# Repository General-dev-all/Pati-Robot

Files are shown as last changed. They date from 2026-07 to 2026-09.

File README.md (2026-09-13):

# Pati

A voice companion robot for children, built on an ESP32-S3.

Pati runs no local model. Audio streams from the device to the Gemini
Live API over a raw WebSocket and returns to the speaker the same way.
No companion app, no intermediate server, no pairing step. Settings are
managed from a web panel served by the robot itself.

The hardware is one part — an M5Stack StickS3 — with the microphone,
speaker, display and battery already inside it. Nothing is soldered.

<p align="center">
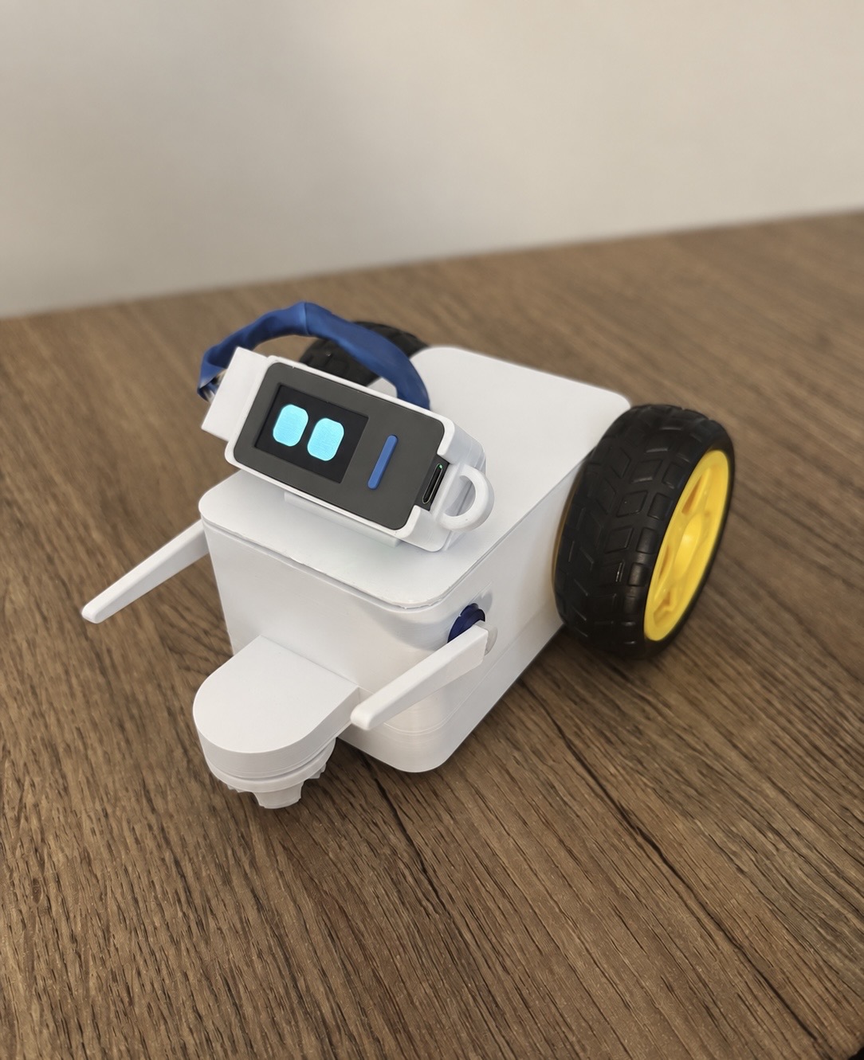
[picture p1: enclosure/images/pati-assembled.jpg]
Pati, assembled
  
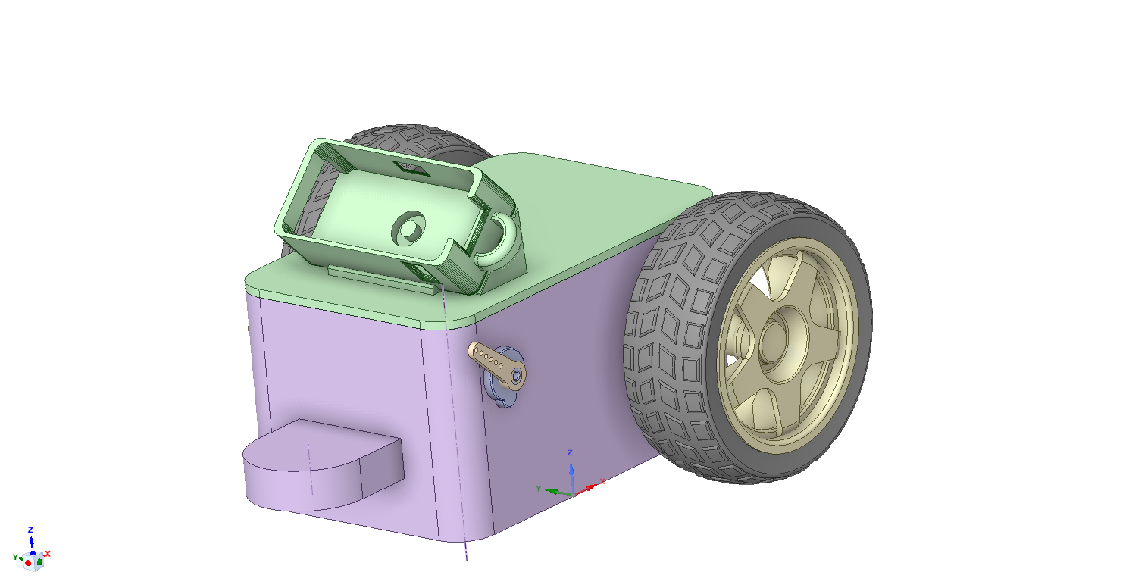
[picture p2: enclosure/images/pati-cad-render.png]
Pati in CAD
  
</p>
<p align="center"><sub>The printed body, assembled &nbsp;·&nbsp; the same assembly in CAD</sub></p>

<p align="center">
  <a href="https://www.youtube.com/watch?v=BEeX3aKE_l4">
    Pati in action — watch on YouTube
  </a>
</p>
<p align="center"><a href="https://www.youtube.com/watch?v=BEeX3aKE_l4"><b>▶ Watch Pati in action</b></a></p>

The body is optional and printable — STLs and editable CAD source are in
[`enclosure/`](enclosure/). Without it Pati still talks, listens and
shows its eyes; the body adds two wheels and two arms.

**Status.** Microphone, speaker, display, eyes, Wi-Fi, panel and Gemini
conversation were verified on a real StickS3 on September 1, 2026.
Battery operation is still unstable: speaking can trigger a reset.
The September 5 code review fixed a playback-related eye power-mode bug;
its effect on real battery resets still needs device testing. See
[`firmware/PIL.md`](firmware/PIL.md) for measurements and remaining work.

---

## Layout

```
firmware/    ESP-IDF v5.5 application
panel/       Parent panel — one web page, served from disk during
             development and compiled into the firmware for the device
prototype/   Python reference implementation; the host tests compare
             firmware behaviour against it
enclosure/   The printable body: STLs ready to slice, editable CAD
             source, and the assembly notes
```

The devkit's assembly guide, wiring diagram and printed parts are not
here. They describe hardware that no longer exists, so they live with
it on the `devkit` branch rather than misleading anyone on `main`.

`panel/` is a single source. The page is not duplicated for the device
build, so a firmware update carries the panel with it.

---

## Hardware

One part. **M5Stack StickS3** (SKU K150) — nothing is wired, nothing is
soldered.

| Inside it | |
|---|---|
| ESP32-S3-PICO-1-N8R8 | 8 MB flash, 8 MB octal PSRAM |
| ES8311 | mono audio codec, configured over I2C, one shared I2S bus |
| MEMS microphone | 65 dB SNR |
| AW8737A + 8 Ω 1 W speaker | amplifier enabled through the M5PM1, not from a GPIO |
| ST7789P3 | 135×240 display, used in landscape as 240×135 |
| M5PM1 | power management, battery charging, the power button |
| 250 mAh battery, 2 buttons, BMI270 IMU, IR | 48 × 24 × 15 mm |

Pin assignments have a single source:
[`firmware/main/pati_pinler.h`](firmware/main/pati_pinler.h).

Three things about this board are not obvious and each one fails
silently:

**The microphone, the speaker and the display backlight are not powered
at boot.** They sit on the M5PM1's `L3B` rail, which the Arduino library
turns on during its own init. On bare ESP-IDF nothing turns it on for
you. Miss it and all three are dead while every call still returns
`ESP_OK`. [`pati_guc.cpp`](firmware/main/pati_guc.cpp) does it.

**The microphone and the speaker share one I2S bus, so they share one
sample rate.** Gemini wants 16 kHz in and gives 24 kHz out; neither is
possible directly. The bus runs at 48 kHz and both directions are
resampled — see [Voice](#voice).

**Use the verified ESP32 signal directions:** GPIO14 is output to the
codec (speaker), GPIO16 is input from the codec (microphone). The
peripheral row label led to these being reversed during the first port.

First boot, step by step, with the symptom-to-line mapping for
everything that cannot be checked without the board:
[`firmware/ILK-ACILIS.md`](firmware/ILK-ACILIS.md) (Turkish).

### The previous Pati

Until August 2026 this was a hand-wired ESP32-S3 devkit with an INMP441,
a MAX98357A and a 240×240 display — thirteen soldered wires. It works
and is kept, not deleted:

```
git switch --detach v2.2.8-devkit     # source
```

Its built `pati.bin` is in the `v2.2.8` release. The branch also carries
what `main` no longer does: `assembly/REHBER.html` (the soldering guide,
Turkish), the wiring diagram, and **that board's** printed parts — which
are not the ones in [`enclosure/`](enclosure/). Those describe a device
that no longer exists.

⚠️ **Do not run this firmware on that board.** Same chip family, so it
flashes and boots, and the update manifest carries no hardware field. It
refuses to run instead: at boot it probes for the ES8311 and, if absent,
declines to mark itself valid so the bootloader rolls back. That
recovery only exists for an image that arrived over the air — one
flashed by cable has nothing to roll back to.

---

## Body

Pati works on its own. The body is optional: it adds two driven wheels
and two servo arms, and it prints on a home 3D printer. Files, parts
list and assembly notes are in [`enclosure/`](enclosure/).

🔴 **The two front wheels must be ball casters, and they print too**
(`enclosure/print/ball-caster.stl`, print-in-place — the ball comes out
of the printer already turning inside its socket). This is not a styling
choice. With fixed-axle front wheels the chassis sits on a rail: it
rolls freely fore and aft but resists sliding sideways, so the torque
that cannot become rotation escapes along the only unresisted axis and
**Pati creeps forward while turning in place**. Three firmware releases
tried to fix that in software and none of them could — the gesture table
already sums to zero rotation by construction. Swapping the front wheels
ended it.

🔴 **Pati turns in place. It never drives itself anywhere.** There is no
cliff sensor, so a robot that could travel on its own would eventually
walk off a table. The whole gesture system is built around one
guarantee: the two wheels always turn in opposite directions, so net
displacement is zero. Driving across a table is possible only from the
panel, under a child's finger, behind a 600 ms dead-man timer.

🔴 **Motor and servo power never reaches the StickS3.** Every one of the
eight wires from the body to the Stick is either ground or the Stick's
own output; the 6 V rail stays inside the body. This is not a caution
note — it is the reason the pins were chosen that way. With the rule set
up like this, the worst outcome of a wire slipping onto the wrong pin is
"a motor runs continuously", not a dead board.

### Wiring

Wire colors in both diagrams match the real assembly. Same diagram, two
languages — the parts and pin numbers are identical.

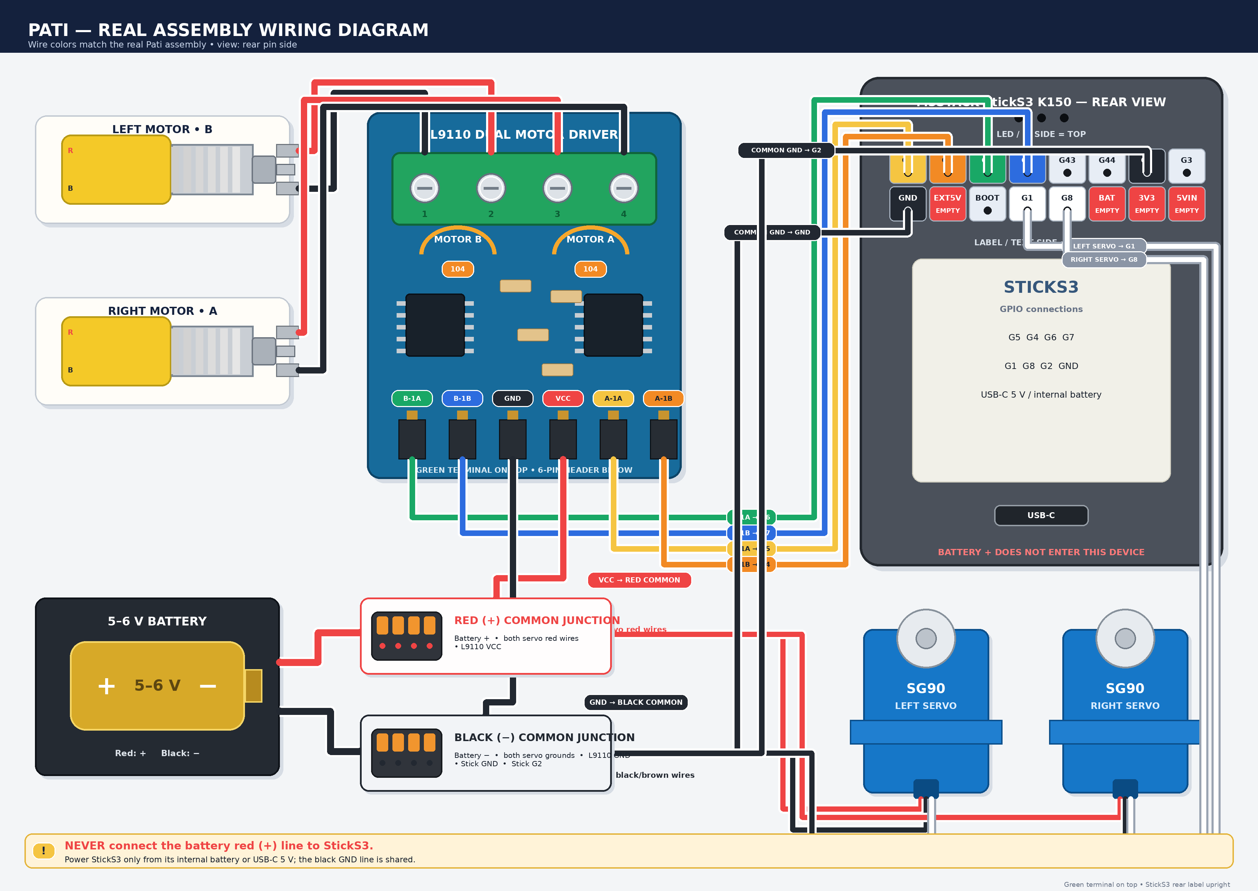
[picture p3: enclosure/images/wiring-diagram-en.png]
Wiring diagram, English


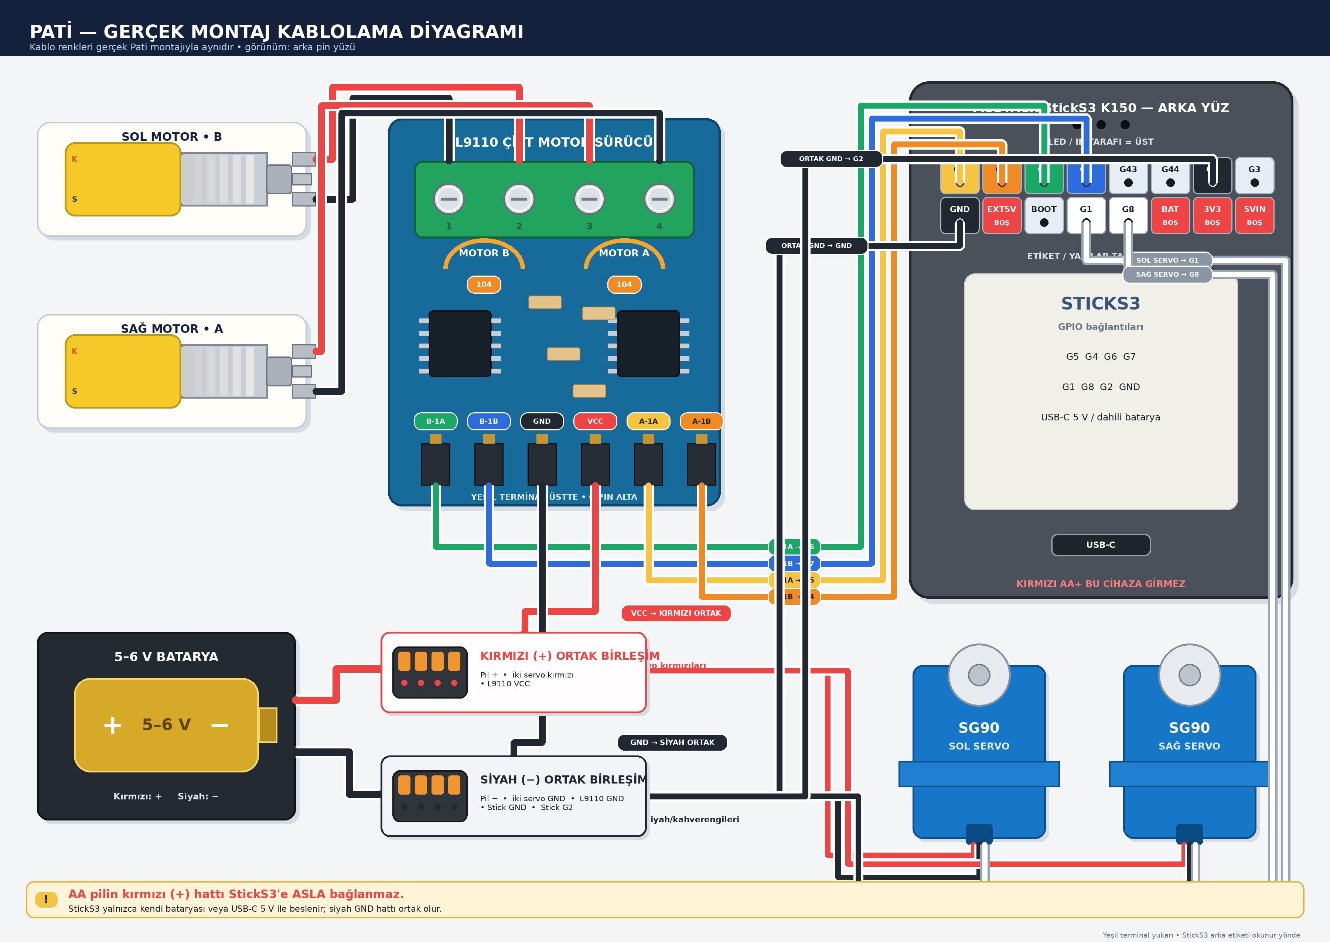
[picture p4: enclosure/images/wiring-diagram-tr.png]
Kablolama diyagramı, Türkçe


There is a third, different document:
[`firmware/Pati_Tek_Bakis_Kablolama_Diyagrami.png`](firmware/Pati_Tek_Bakis_Kablolama_Diyagrami.png)
(Turkish) is not another copy of these — it is the step-by-step pin
table: which way to hold the connector, the L9110 pin map, the power
junctions, and the first-power-up checklist. Use the diagrams above to
see *where the wires go*, and that one to check *each pin before
switching on*.

Pin assignments, commissioning measurements and the numbers still
waiting to be measured: [`firmware/BEDEN.md`](firmware/BEDEN.md)
(Turkish).

---

## Build

Requires ESP-IDF v5.5. On Windows use PowerShell — `idf_tools.py`
refuses to run under MSYS.

```
. "$IDF_PATH/export.ps1"
cd firmware
idf.py -p <PORT> flash monitor
```

Nothing to fill in first. The Wi-Fi credentials and the Gemini key are
both entered on the device — the first through the captive portal, the
second through the panel.

`firmware/KARTA-YUKLE.bat` does the same on Windows and finds the
serial port itself.

No API key is built in. The Gemini key is entered from the parent panel
and stored on the device, so the image contains no secret and can be
published. The partition table is custom
([`firmware/partitions.csv`](firmware/partitions.csv)) and must be
written over USB — `idf.py flash`, not `app-flash`.

## Updates

Push. GitHub builds the firmware and publishes a release holding
`pati.bin` and a generated `surum.json`; the device polls the latter and
downloads the former. No update server, no companion app, nothing to
upload by hand. Details in
[`firmware/SURUM-NASIL-CIKARILIR.md`](firmware/SURUM-NASIL-CIKARILIR.md).

CI picks the version rather than asking for it: the patch of the last
release, plus one. A larger number written into
[`firmware/surum.txt`](firmware/surum.txt) by hand is honoured, a
smaller one ignored. The line under it is the single sentence the parent
sees, and a release with no note is refused.

Publishing on every push is deliberate here. Forgetting to raise a
version produced no error and no release — the robot simply stayed
behind and nothing said so. A push to this repository means the change
was tested and is meant to reach the child's room, so that is what it
does. Only `firmware/` and `panel/` trigger it, since only those end up
in the image.

The manifest is a release asset rather than a committed file because a
push publishes a committed file immediately but does not build the
binary. For the minutes in between, the panel would offer an update that
404s. Sharing a release makes the manifest unable to exist before the
image it describes.

The binary is not committed. The panel is compiled into it, so a panel
change ships as a firmware update — which is why the two cannot drift.

The build needs no secrets, which is what makes CI possible at all: the
key and the Wi-Fi credentials both live in the device's NVS, and no
source file reads them from the configuration.

Rollback is enabled: a new image boots on trial and is only marked good
once the network stack and panel are up. An image that cannot get that
far is reverted by the bootloader on the next power cycle.

---

## Voice

Pati sounds like a child. That is not a Gemini setting — the Live API
exposes no pitch or rate control, only a voice name. Puck's raw voice is
an adult man's. The character comes entirely from **playing the reply
1.30× fast**, which raises the pitch by about the same amount.

On the old board this was one line: run the speaker's I2S clock at
31 200 Hz instead of 24 000. The StickS3 cannot do that — the speaker
shares its clock with the microphone, and moving it would break capture.

So the multiplier moved into software. The bus runs at 48 kHz and every
output sample steps `çarpan / 2` through the 24 kHz source — 0.65 at
1.30× — interpolating between samples. The step is always below 1
across the whole adjustable range (0.80–1.60 → 0.40–0.80), which is the
point: below 1 you interpolate and nothing aliases. Above 1 you would be
decimating, and Pati would rasp.

Capture goes the other way: 48 kHz down to the 16 kHz Gemini wants, an
exact 3:1 ratio, averaging each group of three. The averaging is also a
crude low-pass, which plain decimation would not be.

[`pati_ornekleyici.hpp`](firmware/main/pati_ornekleyici.hpp) holds the
maths, and it is a header rather than part of `pati_ses.cpp` because the
host test includes the same file — the test measures the real code, not
a copy. It found two real defects: output drifting apart depending on
how the audio was sliced, and phase loss over a long stream. Both came
from accumulating position in a single `float`, whose precision decays
as the value grows. Position is now an integer index plus a fraction
kept in `[0, 1)`.

---

## Tests

```
firmware/test/derle.bat     C++ eye renderer vs. the browser renderer,
                            pixel by pixel; C++ memory engine vs. Python;
                            the resampler that produces Pati's voice
python prototype/testler.py prototype behaviour
node panel/panel_test.mjs   the panel loads against a stub DOM, in each
                            of the four sample data sets
```

`ses_karsilastir` also writes two WAVs from a raw 24 kHz Gemini capture,
for listening rather than asserting:

```
firmware/test/ses_karsilastir.exe --pcm kayit.pcm --cikti .
```

One is what the old board played, the other is what the new path
produces. They have to sound the same.

The panel check exists because a missing element makes `querySelector`
return null, and the resulting throw stops the module — so the failure
is not the card that was edited, it is every card below it. Nothing on
screen says why.

The host comparisons exist because a port that compiles is not a port
that behaves identically. Generated headers are produced by
`prompt_uret.py` and `goz_uret.mjs`, which read their output back and
compare it to the source; they are not edited by hand.

---

## Operation

With no reachable saved network the device opens its own access point
and serves a captive portal for Wi-Fi setup. Once connected it
advertises itself over mDNS and the panel is reachable at `pati.local`.

The panel covers voice and rate, response latency, sleep threshold,
usage and estimated cost, the robot's name, the facts it has retained,
the Gemini key, and firmware updates. The interface is Turkish only.

Setup is Wi-Fi, then the key. Until a key is entered the robot has a
face but no voice, and the panel says so rather than leaving the parent
to guess.

When Google rejects a request the panel distinguishes the cases, because
the parent's next action differs: a rejected key needs replacing, an
exhausted quota needs credit, and an unreachable network needs nothing
at all. Collapsing the three would invite paying for an outage.

---

## Privacy

No child data is committed here. API keys, Wi-Fi credentials, retained
memory, usage counters and transcripts are excluded by `.gitignore`.

On the device, memory is stored in NVS and written atomically, since
the expected shutdown is a power cut. It can be cleared from the panel.

---

## License

MIT — see [LICENSE](LICENSE), which also lists third-party components.

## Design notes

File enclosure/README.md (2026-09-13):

# Gövde — 3B baskı parçaları

**Gövde artık var ve basılabiliyor.** Bu klasör, Pati'yi kendi yapmak
isteyen biri için gereken bütün parçaları taşıyor: dilimleyiciye
doğrudan verilebilen STL'ler ve tasarımı değiştirmek isteyenler için
düzenlenebilir CAD kaynağı.

<p align="center">
  Pati, monte edilmis hali
  Pati, CAD gorunumu
</p>

---

## Ne nerede

### `print/` — dilimleyiciye doğrudan verilir

| Dosya | Ne |
|---|---|
| `body.stl` | Gövdenin kendisi. Motorlar, sürücü ve besleme bunun içinde |
| `body-top.stl` | Üst kapak. StickS3 yuvası bunun üzerinde |
| `arm.stl` | Kol. **İki adet basılıyor** — servo boynuzuna geçiyor |
| `sticks3-case.stl` | StickS3'ün kızağa oturan kasası |
| `sticks3-cable-plug.stl` | Hat2-Bus şerit kablosunu Stick'e hizalayan tutucu |
| `ball-caster.stl` | **Ön sarhoş teker.** İki adet basılıyor — aşağıya bak |

### `cad/` — tasarımı değiştirmek için

Üçü de **aynı montajın** farklı biçimleri:

| Dosya | Ne zaman |
|---|---|
| `pati-assembly.step` | **Önce bunu dene.** Her CAD programı okuyor |
| `pati-assembly.x_t` | Parasolid çekirdekli programlarda (SolidWorks, Solid Edge, NX) daha temiz geliyor |
| `pati-assembly.scdocx` | SpaceClaim'in kendi biçimi — tasarım ağacıyla birlikte |

⚠️ **STL'i düzenlemeye çalışma.** STL yalnızca üçgen yüzeyler tutuyor;
ölçüyü 2 mm büyütmek gibi bir şey orada ağrılı, CAD kaynağında bir
sayı. Değişiklik `cad/`'de yapılıp STL yeniden dışa aktarılmalı.

---

## 🔴 Ön tekerlekler DÖNEBİLEN (caster) olmalı — bu ölçülmüş bir ders

Gövdede dört tekerlek var: arkada iki tahrik tekerleği, önde iki
destek. **Öndekiler sabit akslı olursa Pati kendi etrafında dönerken
İLERİ KAYIYOR.**

Sebep mekanik: sabit bir tekerlek kendi ekseninde dirençsiz yuvarlanıp
yana kaymaya direniyor, yani gövdeyi bir rayın üstüne koyuyor. Dönüşe
çevrilemeyen kuvvet, direnç görmediği tek eksene — ileri — kaçıyor.

⚠️ **Bu yazılımdan düzeltilemiyor ve üç sürüm boyunca denendi.** Pati'nin
jest tablosunda net dönüş yapısal olarak sıfır (iki tekerlek her zaman
ters yönde) ve konak testi bunu her girdide tarıyor — yani komut zaten
doğruydu, kayan şey fizikti. Ön tekerlekler dönebilen (İngilizcesi
*ball caster*, Türkçede "sarhoş teker", satın alırken "üniversal bilya")
tipiyle değiştirilince kayma bitti (13.09.2026). Ayrıntı:
[`../firmware/BEDEN.md`](../firmware/BEDEN.md).

**Neden önemli:** Pati'de uçurum sensörü yok. Kendi kararıyla ilerleyen
bir robot eninde sonunda masadan düşer, ve bu tasarımın tamamı Pati'nin
yalnızca *yerinde dönmesi* üzerine kurulu.

### `ball-caster.stl` — satın almaya gerek yok, basılıyor

**Yerinde basılan (print-in-place) bir parça.** Yuva ve bilya tek
dosyada, ayrı ayrı montaj yok: baskı bitince bilya yuvanın içinde
kendiliğinden dönüyor.

Ölçüler dosyadan okundu, tahmin değil:

| | |
|---|---|
| Dış ölçü | 31 × 31 × 21 mm |
| Bilya çapı | 16,0 mm |
| Yuva–bilya boşluğu | **0,177 mm**, her yerde eşit |
| Adet | **2** (ön tekerleklerin ikisi de) |

🔴 **0,177 mm dar bir boşluk ve bu parçanın tek riski orada.** Yerinde
basılan parçalarda alışılmış aralık 0,2–0,4 mm; bu onun altında. İyi
ayarlanmış bir yazıcıda sorun çıkarmaz, ama fazla akıtan (over-extrude)
ya da kalibresi kaymış bir yazıcıda **bilya yuvaya kaynar ve dönmez**.

Belirtisi baskıdan hemen sonra anlaşılıyor: bilyayı parmakla
çeviremiyorsan kaynamıştır. Kurtarmayı denemek yerine akış oranını
düşürüp yeniden basmak daha hızlı — kaynamış bir bilyayı zorlamak
yuvayı kırıyor.

⚠️ **Dönmeyen bir sarhoş teker, sabit akslı tekerlekle aynı şeydir** —
yani yukarıdaki ileri kayma sorunu geri gelir. Bu parça basıldıktan
sonra **ikisi de elle kontrol edilmeli.**

---

## Baskı dışında gereken parçalar

| Parça | Not |
|---|---|
| 2 × TT redüktörlü DC motor + tekerlek | sarı, yaygın tip |
| ~~2 × dönebilen ön tekerlek~~ | **satın alma — `ball-caster.stl` basılıyor** |
| 1 × L9110S çift kanal motor sürücü | |
| 2 × SG90 sınıfı mini servo | kollar |
| Besleme | 4'lü AA yuvası **ya da** powerbank |
| M5Stack StickS3 (SKU K150) | Pati'nin kendisi |

🔴 **Motor ve servo beslemesi StickS3'ten ALINMIYOR.** Gövdeden Stick'e
giden sekiz kablonun hepsi ya toprak ya Stick'in kendi çıkışı; 6 V
hattı gövdenin içinde kalıyor. Bu bir uyarı değil, **pin seçiminin
sebebi**: kural böyle kurulunca yanlış pine kayan bir kablonun en kötü
sonucu "motor sürekli dönüyor" oluyor, yanmış bir kart değil.

### Kablolama

Her iki diyagramdaki kablo renkleri **gerçek montajla aynı**. Aynı
şema, iki dil — parçalar ve pin numaraları birebir.

Kablolama diyagramı, Türkçe

Wiring diagram, English

⚠️ **Üçüncü bir belge daha var ve o bunların kopyası DEĞİL:**
[`../firmware/Pati_Tek_Bakis_Kablolama_Diyagrami.png`](../firmware/Pati_Tek_Bakis_Kablolama_Diyagrami.png)
adım adım **pin tablosu** — soketin hangi yönde tutulacağı, L9110 pin
haritası, ortak güç birleşimleri ve ilk çalıştırma kontrol listesi.

**Hangisi ne zaman:** yukarıdaki şemalar *kablo nereye gidiyor* diye
bakarken, pin tablosu *açmadan önce her pini tek tek doğrularken*.

⚠️ İkisinin dosya adı benziyor ama içerikleri farklı. Birini
diğerinin yerine kullanmak, doğruladığını sanıp doğrulamamak olur.

Pin atamaları ve devreye alma ölçümleri:
[`../firmware/BEDEN.md`](../firmware/BEDEN.md)

---

## Monte ederken

🔴 **Kolun gidebileceği aralık MEKANİK bir sınır.** Bu gövdede ölçüldü
(09.09.2026): sol kol **%10–%70**, sağ kol **%0–%100**. Sol kol aşağıda
tekerleğe, yukarıda üstteki kabloya çarpıyor. Aşılırsa kol dayanır,
servo dönmeye çalışıp durur, ısınır ve **yanar** — belirtisi sürekli
bir vızıltıdır.

Aralık panelden ayarlanıyor ve **fabrika ayarlarına dönünce
silinmiyor**; kaybolması donanıma zarar verdiği için ayrı bir flash
bölümünde duruyor.

⚠️ **Servolar ters takılabilir** ve ikinci gövdede öyle oldu.
"Kolunu kaldır" deyince kol aşağı iniyorsa panelde **"Kol yönünü ters
çevir"** anahtarı var. Aynısı sürüş için de var: joystick'i ileri
itince Pati geri gidiyorsa **"İleri/geri yönünü ters çevir"**, sağa
itince sola dönüyorsa **"Sağ/sol yönünü ters çevir"**. Üçü birbirinden
bağımsız.

⚠️ **Mikrofon, hoparlör ve USB-C deliği kapatılmamalı.** Üçü de
Stick'in gövdesinde. Hoparlör 1 W ve zaten kısık; önüne konan her
katman daha da kısıyor ve **yazılımdan telafi edilemiyor** (ses tavanı
pil yüzünden sınırlı — [`../firmware/PIL.md`](../firmware/PIL.md)).
USB-C hem şarj hem de bir şey ters giderse tek kurtarma yolu.

⚠️ **Metal kasalı powerbank'i Stick'in altına koyarken dikkat.**
Ölçülen wifi sinyali −76…−91 dBm ve zayıf sinyal brownout'un bilinen
bir etkeni. Henüz doğrulanmadı ama şüphe, powerbank'in ve Stick'in
üstünden geçen şerit kablonun anteni gölgelemesi.

---

## Henüz yazılmamış olanlar

**Tahmin değil ölçüm** kuralı burada da geçerli — bu sayılar
ölçülmediği için yazılmadı, uydurulmadı:

- Katman yüksekliği, doluluk oranı, destek gerekip gerekmediği
- `ball-caster.stl`'in hangi yüzü tablaya bakacak (bilya yuvadan
  yukarı taşıyor; yönü baskı başarısını doğrudan etkiler)
- Filament cinsi (fotoğraftaki baskı beyaz, cinsi kayıtlı değil)
- Baskı süresi ve malzeme miktarı
- Vida ölçüleri

Basan biri bunları ölçerse buraya eklenmeli.

---

## Eski gövde

Ağustos 2026'ya kadar Pati elle lehimlenmiş bir ESP32-S3 devkit'ti ve
onun da kendi kabuğu vardı — iki parçalı bir kafa, bir gövde, bir
taban. O donanım emekli oldu ve parçalar onunla birlikte arşivde:

```
git switch --detach v2.2.8-devkit
ls enclosure/
```

Silinmediler; buradan kaldırılmalarının tek sebebi yanıltıcı olmaları.
Ölçüleri artık var olmayan bir cihaza ait.

M5Stack StickS3'ün kendi CAD dosyaları da yayımlanmış durumda — kasayı
sıfırdan çizmek gerekirse tahmin etmeye gerek yok:

<https://github.com/m5stack/M5_Hardware/tree/master/Products/K150_StickS3/Structures>

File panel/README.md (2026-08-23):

# panel

The parent panel: one page, the robot's face on top and its settings
below.

These files are a **single source**. During development they are served
from disk; on the device the same files are compiled into the firmware
image with `EMBED_FILES`. They are never copied or forked, so the panel
seen while developing and the panel served by the robot cannot drift
apart. A firmware update carries the panel with it.

## Files

| File | Role |
|---|---|
| `index.html` | Page structure |
| `stil.css` | Styling |
| `pati.js` | Panel logic; talks to the robot over REST, or to the prototype over WebSocket |
| `gozler240.js` | Eye renderer — the reference implementation ported to C++ |
| `mikrofon.js` | Browser microphone capture (development only) |
| `ornek.js` | Sample data for bench mode |

`gozler240.js` writes pixels into a 240×135 buffer rather than using
canvas drawing commands, because the device renders the same geometry
without a graphics library. The two are compared pixel by pixel in the
host tests.

## Development

```
TELEFONDAN-INCELE.bat    serve on the local network (port 8756)
PAYLAS.bat               open an HTTPS tunnel to that server
```

Plain HTTP is enough to review layout, but browsers only grant
microphone access over HTTPS — the tunnel exists for that. `PAYLAS.bat`
refuses to open a tunnel when nothing is listening, since an empty
tunnel returns 502 and looks like a device fault.

## Bench mode

Opened without a robot, the page detects this and falls back to sample
data, marking itself with a banner so measurements are not mistaken for
real ones. With a robot present it polls `/api/durum` and switches to
live values.

The key and update cards have no counterpart on the Python side — one
lives in the device's NVS, the other writes the device's own flash. In
bench mode the page simulates both, so the design can be reviewed from a
phone and cannot quietly differ from what the parent sees.

```
node panel_test.mjs         loads the page against a stub DOM, once per
                            sample data set, and fails on a missing
                            element, an unbound button, or a card that
                            never drew
```

It also asserts what the sample sets exist to cover: no warning when the
key works, a warning when it has never been entered, and — the one that
matters — no red key warning when the network is simply down. Those
three lead to different parental actions, and conflating them invites
paying for an outage.

The user interface is Turkish only.

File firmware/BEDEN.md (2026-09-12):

# Pati'nin bedeni

İki tekerlek, iki kol, kendi pili. StickS3 bedene takılınca Pati bunu
kendi anlıyor; takılı değilken bedenle ilgili hiçbir şey görünmüyor.

**Durum (06.09.2026):** algılama, panel kumandası ve **motorlar
çalışıyor** — motorlar 3.1.1 ile panelden sürülüyor. **Servolar açık iş**
(aşağıda ayrı bölüm). Ölü bölge hâlâ ölçülmedi ve öyle işaretli.
Bir sayı iddia ediliyorsa nereden geldiği yazılı.

📐 **Kabloyu takacak kişi için tek sayfa:
[`Pati_Tek_Bakis_Kablolama_Diyagrami.png`](Pati_Tek_Bakis_Kablolama_Diyagrami.png)** — pin haritası,
L9110 bağlantıları, ortak ekler ve ilk çalıştırma sırası tek bakışta.
Kablo renkleri gerçek montaja göre. Aşağıdaki metin onun gerekçesi.

⚠️ Diyagram başlığı **ÜST/ALT** diye konumluyor (cihazı elde tutarken
görünen hal); bu belge ve `pati_pinler.h` M5Stack'in tablosundaki gibi
**SOL/SAĞ** diyor. Aynı şey: M5Stack'in "sol" sütunu (tek numaralar)
diyagramda ALT sırada. Pin numaraları ikisinde de aynı — şüphede
kalırsan **pin numarasına** güven.

---

## 🔴 Tek pazarlıksız kural

> **AA pilin (+) ucu StickS3'e hiçbir şekilde gitmiyor.
> Gövdeden Stick'e giden sekiz kablonun hiçbiri 6 V taşımıyor.**

Sebebi Hat2-Bus'ın dizilişi: sinyal pinlerinin arasında **BAT** (lityum
hücrenin kendi ucu), **5V_IN**, **3V3_L2** ve **EXT_5V** duruyor. Oraya
6 V girerse hücre ve M5PM1 gider.

Bu bir uyarı değil, **pin seçiminin sebebi**. Kural böyle kurulunca bir
kablo yanlış pine kaysa bile en kötü ihtimal "motor sürekli dönüyor"
oluyor — yakmıyor.

Ayrı besleme ayrıca pazarlık konusu değil: 250 mAh'lik hücre
01.09.2026'da **yalnızca hoparlör akımıyla** brownout yaşadı
(`TESHIS.md`).

---

## Bağlantı

Kaynak: docs.m5stack.com/en/core/StickS3 → PinMap → Hat2-Bus
(06.09.2026). Pin numaraları `main/pati_pinler.h`'de, tek kaynak orası.

```
        SOL              SAĞ
  GND    1  ────────  2   G5     sol motor ileri   (L9110 A-1A)
  EXT_5V 3  ────────  4   G4     sol motor geri    (L9110 A-1B)
  Boot   5  ────────  6   G6     sağ motor ileri   (L9110 B-1A)
  G1     7  ────────  8   G7     sağ motor geri    (L9110 B-1B)
  G8     9  ──────── 10   G43
  BAT   11  ──────── 12   G44
  3V3_L2 13 ──────── 14   G2     beden algılama
  5V_IN 15  ──────── 16   G3

  pin 1  → AA (−)                toprak
  pin 7  → servo 1 sinyal        sol kol
  pin 9  → servo 2 sinyal        sağ kol
  pin 14 → AA (−), ikinci uç     beden algılama
```

Sıralamanın üç gerekçesi var:

1. **Motorlar hep sağ sütunda.** Sağ sütunun tamamı GPIO — orada tek bir
   güç pini yok. Motor kablosunun yanlışlıkla BAT'a düşmesi imkânsız.
2. **Servolar sol sütunda.** Bir servo sinyali kayıp BAT'a düşerse servo
   geçersiz darbe görür ve durur. Motor kablosu kaysaydı motor sürekli
   dönerdi — yani Pati masadan düşerdi. Riski, sonucu daha zararsız olan
   uca kaydırdık.
3. **G43 / G44 bilerek boş.** ESP32-S3'ün ROM UART0'ı orada ve her
   açılışta G43'ten önyükleyici çöpü çıkıyor. Motor girişine bağlı
   olsaydı Pati her sıfırlamada seğirirdi — üstelik Pati brownout
   yüzünden sık sıfırlanıyor (`PIL.md`).

G0 (Boot) ve G3 strapping pini olduğu için kullanılmıyor.

### Gövdenin içi

```
AA (+) ──┬── L9110 VCC
         ├── servo 1 kırmızı
         └── servo 2 kırmızı

AA (−) ──┬── L9110 GND
         ├── servo 1 kahve/siyah
         ├── servo 2 kahve/siyah
         ├── Stick Hat pin 1   (toprak)
         └── Stick Hat pin 14  (beden algılama)

L9110 MOTOR-A vidalı klemens ── sol motor
L9110 MOTOR-B vidalı klemens ── sağ motor
```

Lehim yok. ⚠️ Motor durduğunda (stall) 1 A'in üstünde akım geçiyor:
gevşek bir ek ısınır ve zamanla kopar.

L9110 lojik girişleri 2,5 V üstünü yüksek sayıyor (ESP32'nin 3,3 V'u
yetiyor), besleme aralığı 2,5–12 V.

---

## Beden algılama

G2 içeri çekmeli giriş. Beden yokken pin havada → `1`; takılınca gövde
toprağına bağlanıp `0`. Sıfır ek parça, tek kablo.

Karar **1 saniye kararlı** kalınca değişiyor: takıp çıkarırken kontak
sekiyor ve sekmeyi durum değişikliği saymak, panelin kumanda kartını
açıp kapatması demek olurdu.

⚠️ **Bunun bilmediği şey: AA pil anahtarı açık mı.** "Beden takılı"
diyor, "beden çalışıyor" demiyor. Panel bunu yazıyor. Ölçmenin yolu var
ama parça istiyor (AA gerilimini bölücüyle ADC'ye vermek, iki direnç);
yapılmadı.

Kaç kez takıldığı sayılıyor (`/api/durum` → `beden.takma`). Kablo
temassızsa bu sayı hızla artıyor — "beden ara ara kayboluyor"
şikâyetinin sayısal karşılığı.

---

## Yazılım

| Dosya | Ne yapıyor |
|---|---|
| `main/pati_beden.hpp/.cpp` | katmanın tamamı: algılama, servolar, motorlar, jest motoru, ölü adam |
| `main/pati_beden_matematik.hpp` | donanıma dokunmayan matematik — konak testinde sınanıyor |
| `test/beden_karsilastir.cpp` | 4375 kontrol; `derle.bat`'ın 4. testi |

### Sıcak döngü kuralı

Beden görevi **I2C yapmıyor, kilit almıyor, NVS'e dokunmuyor.** İçindeki
tek donanım teması LEDC yazmaçları ve bir GPIO okuması.

**20 ms'lik döngü yalnızca gerçekten bir şey hareket ederken çalışıyor.**
Boşta görev uyuyor (200 ms) ve komut gelince bildirimle uyandırılıyor.
Yani tuzağa düşecek döngü, zamanın çoğunda hiç var olmuyor.

Bu, `CLAUDE.md`'deki 02.09.2026 gerilemesinin dersi: bir servo döngüsü
doğası gereği 20-50 ms'de bir dönmek istiyor ve bu dosya o tuzağa en
yakın duran yer.

### LEDC dağılımı

| İş | Zamanlayıcı | Kanal | Frekans |
|---|---|---|---|
| Arka ışık *(var olan)* | TIMER_1 | CH1 | — |
| Kollar | TIMER_2 | CH2, CH3 | 50 Hz, 14 bit |
| Motorlar | TIMER_3 | CH4–CH7 | **5 kHz**, 10 bit |

TIMER_0 ve CH0 boş. ESP32-S3'te 4 zamanlayıcı, 8 kanal var (yalnızca
düşük hız kipi).

⚠️ Motor frekansı **ölçülerek** 20 kHz'den 5 kHz'e indi — 20 kHz'de
motorlar hiç dönmüyordu. Gerekçe D adımında.

### Servo susturma

Kol hedefe varıp 250 ms geçince **darbe kesiliyor**. Darbe yoksa servo
tutma torku uygulamıyor ve susuyor — mikrofon 10 cm ötede ve sürekli
açık. Yan faydası: boştaki akım sıfır.

⚠️ Hafif plastik bir kol kendi ağırlığıyla düşmüyorsa bu bedava.
Düşüyorsa dinlenme açısı yerçekimine yaslanacak şekilde seçilmeli
(`KOL_DINLENME_DERECE`).

### Yumuşak kalkış — motorlar anlık tam güce geçmiyor

Kullanıcının açık isteği (06.09.2026). Teknik karşılığı: bir DC motorun
en yüksek akımı **kalkış anında** oluyor (rotor dururken sargı direnci
dışında akımı sınırlayan bir şey yok). O tepe AA hattında gerilim
çöküşü yapıyor ve aynı hatta duran servolar çöküşü görüyor.

0 → %100 **400 ms** (20 ms'lik tikte 5 birim). Çocuğun kumandasında
hissedilmiyor, akım tepesini düşürmeye yetiyor.

⚠️ **Durmak rampadan geçmiyor.** Sıfıra iniş anında; ölü adam
zamanlayıcısı ya da parmağın kalkması kademeli olamaz — o gecikme masa
kenarında santimetre demek.

Yön değiştirme rampadan geçtiği için değer önce 0'ı ziyaret ediyor:
sert ters çevirme (en kötü akım tepesi) kendiliğinden ortadan kalkıyor.
Konak testi üçünü de koruyor (`beden_karsilastir.cpp` · 5. bölüm).

### 🔴 Kalkmak ile gitmeye devam etmek ayrı iki sayı

Bu, motor tarafındaki en önemli fikir ve 06.09.2026'da gerçek kartta
ölçülerek öğrenildi.

Motor **dururken** yüksek güç istiyor (durgun rotor + redüktör
sürtünmesi), ama bir kez döndüğünde çok daha azı yetiyor. İkisi tek bir
sayıya bağlandığında robot ya **ötüyor** ya **fırlıyor**; arada
kullanılabilir yer kalmıyor. Kullanıcının şikâyeti buydu:
*"çok hızlı dönüyorlar, bu kadar hız olmaz çocuk için."*

| Sayı | Değer | Ne yapıyor |
|---|---|---|
| `MOTOR_KALKIS_DUTY` | %85 | Yalnızca dururken harekete geçerken |
| `MOTOR_KALKIS_MS` | 180 ms | Darbe penceresi; 100 ms'de tepeye çıkıyor |
| `MOTOR_EN_AZ_DUTY` | %17 | Ondan sonraki **gitme** tabanı |
| `hiz_egrisi` | karesel | Yarım itişte hızın dörtte biri |

Darbenin kendisi de **rampalı** (`MOTOR_KALKIS_ADIM`, 100 ms'de tepeye)
— anlık sıçrama yok. Bu, kullanıcının "anlık tam güç yapma" kuralına
bilinçli bir istisna ve **onayı alındı**. Farkı büyüklükte: kuralı
doğuran olay bitmiş pille 5 saniye kesintisiz tam güçtü.

Rampa adımı üç ayrı değer, çünkü üç durumun riski aynı değil:

| Durum | Adım/tik | Neden |
|---|---|---|
| Hızlanma | 5 | Akım tepesini düşüren yer burası, en yavaş bu olmalı |
| Yavaşlama | 15 | Akım zaten düşüyor; hızlı inmek istenen yavaş hıza çabuk oturtuyor |
| Kalkış darbesi | 20 | Sürtünmeyi kıracak kadar hızlı, yine de rampalı |

⚠️ %17 hâlâ **ölçülmedi** — ama artık bir kalkış eşiği değil bir gitme
tabanı ve o çok daha bağışlayıcı. Ölçmek için ek koda gerek yok:
tekerlekler takılı, Pati yerde, panelden hız sınırını düşür; motorun
dönmeye devam edemediği (kalkıp hemen durduğu) değer tabandır.

### Ölü adam zamanlayıcısı

Komut gelmeden **600 ms** geçerse motorlar duruyor. Panel dokunma
sürerken 150 ms'de bir gönderiyor; dört paket üst üste kaybolursa
duruyor.

Panelin sıfır göndermesine **güvenmiyoruz**: unutan bir panel, kaçan bir
robot demek. Panel ayrıca sekme arka plana atılınca da durduruyor
(`pointerup` o durumda hiç gelmiyor), ama güvenlik ona bağlı değil.

### 🔴 Özerk hareket — Pati döner, ilerlemez

Pati konuşurken kendiliğinden kıpırdıyor: konuşma başlayınca bir jest,
sonra **3–7 saniye rastgele** bekleme, konuşma sürüyorsa yeni jest.
Sabit aralık iki cümlede fark ediliyor ve mekanik görünüyor.

06.09.2026'da tekerlekler de bu jestlere katıldı. Ondan önce tekerlek
tamamen panele bağlıydı ve gerekçesi şuydu: **Pati'de uçurum sensörü
yok**, masanın kenarını görebileceği hiçbir yol yok, kendi kararıyla
ilerleyen bir Pati eninde sonunda düşer.

**Karar değişti, gerekçe değişmedi.** Eski kural yanlış yerde
duruyordu: yasaklanması gereken *tekerlek* değil, *yer değiştirme*ydi.

Şimdi özerkliğin tamamı tek bir sayıyla anlatılıyor:

```
sol = +teker        sag = -teker
```

İki tekerlek her zaman ters yönde → Pati yerinde döner, yer
değiştirmez. **Bu bir yorumdaki uyarı değil, tipin kendisi:** jest
karesinin tek bir `teker` alanı var, dolayısıyla ileri giden bir jest
*yazılamıyor*. Kuralı bilmeyen biri de bozamıyor.

#### Jest tablosunun üç kuralı

Üçü de `firmware/test/beden_karsilastir.cpp` §7'de zorlanıyor.

| # | Kural | Bozulursa ne olur |
|---|---|---|
| 1 | Tekerlek dönen kare **kol oynatmaz** | Motor kalkışı AA hattında çöküntü yapıyor; o anda hareket eden servo titriyor ya da sıfırlanıyor (06.09.2026'da yaşandı) |
| 2 | Yön değiştirmeden önce **sıfır karesi** var | `motor_rampa` yön değişimini bilerek yavaş geçiyor (5/tik = 400 ms). Araya sıfır konmazsa 150 ms'lik kare boyunca motor yalnızca yavaşlar, hiç dönmez — belirtisi "jest çalışmıyor" olur ve sebebi rampada aranmaz |
| 3 | **Net dönüş sıfır** | Pati her jestten sonra biraz daha başka yöne bakar; çocuğun "ileri" sandığı yön kayar ve kumanda öğrenilemez olur |

Ayrıca bir jestin toplam tekerlek süresi **900 ms**'yi aşamıyor.

🔴 **Dördüncü bir kural 12.09.2026'da eklendi: her tekerlek karesi en az
300 ms.** Gerekçesi ve ölçümü aşağıda ("İleri kayma").

Dönüş hızının üst sınırı **%75** (`JEST_DONUS_EN_COK`); çocuğun
joystick'i hâlâ %100'e çıkabiliyor. Yükselen şey darbe değil,
darbeden *sonraki* sürekli dönüş — tepe akımı değişmiyor.

| Jest | Tekerlek | Kalkış | Ne anlatıyor |
|---|---|---|---|
| `dinlen` `selam` `iki_kol` `alkis` `dusun` | — | — | yalnızca kol |
| `zipla` | — | — | kollarla hızlı zıplama — **kayma maliyeti sıfır** |
| `sevin` | 4 × 320 ms | 4 | dört salınım, sonra kollarla kutlama |
| `titre` | 4 × 280 ms | 4 | tablonun en hızlı dört salınımı — kıkırdama |
| `hayir` | 4 × 300 ms | 4 | sağ-sol: **kafa sallayıp "hayır" demek** |
| `bak_etrafina` | 2 × 440 ms | 2 | yavaş dön, **dur ve bak** (400 ms), geri dön |
| `firildak` | 2 × 600 ms | 2 | tablonun en büyük savurması |
| `dans` | 4 × 320 ms | 4 | hazırlık, dört salınım üst üste, kol koreografisi |

Yön değiştirme boşluğu **40 ms** — sıfırlanamaz (motoru doğrudan ters
çevirmek en kötü akım tepesi) ama en küçük makul değer.

🔴 **Kol karesi iki dönüşün ARASINA konmaz.** Kullanıcının sözü
(13.09.2026): *"1. ve 2. dc motor arası mesafe çok fazla"*. Sebebi
tabloda duruyordu: `dans`'ta iki dönüşün arasında bir kol karesi vardı
ve **kol kareleri kolun varmasını bekliyor** (~180 ms yol + bekleme),
yani iki dönüş arası 40 ms değil **~350 ms** oluyordu. Kollar artık
dönüşlerin önünde ve arkasında.

Yalnızca `hayir` **kendiliğinden seçilmiyor**: rastgele "hayır" demek
tuhaf olurdu, anlam taşıyor. `dans` 13.09.2026'da kendiliğinden
seçilebilir oldu — "uzun" diye dışarıda bırakılmıştı, ama istenen
canlılık tam olarak o.

⚠️ **`hayir` dört kalkışla tek istisna.** İki salınım "hayır" değil
"etrafına baktı" demek olur; anlam salınım *sayısında*. Kendiliğinden
seçilmediği için sürünme birikecek sıklıkta değil.

#### Sıklık — seyreklik bir süs değil

Sırası gelen jestin tekerlekli olma ihtimali **yarı yarıya**, ve iki
tekerlekli jest arasında **en az 12 saniye** var. Yerinde dönüş yer
değiştirmiyor ama tekerlek kayması **ikinci dereceden** bir sürünme
bırakıyor; boşluk o milimetrelerin birikmesine izin vermiyor. Sürekli
kıpırdayan bir robot ayrıca sevimli değil, huzursuz görünüyor.

⚠️ **Biriken şey süre değil, kalkış sayısı** — sürünme kalkış
darbesinde oluyor, dönüşün kendisinde değil. 12.09.2026'da `titre` ve
`dans` dört kalkıştan ikiye indiği için kura 1/3 → 1/2'ye çekilebildi:

| | Jest arası | Kalkış/jest | Kalkış/sn | Dönüş/sn |
|---|---|---|---|---|
| eski (12 sn, 1/3) | ~24,6 sn | 2,67 | 0,108 | 18 ms |
| yeni (12 sn, 1/2) | ~19,6 sn | 2,00 | **0,102** | **35 ms** |

Pati ~%28 daha sık dönüyor, dönüş süresi neredeyse iki katına çıkıyor,
ama dakikadaki kalkış sayısı biraz düşüyor.

🔴 **12 saniye duruyor ve bilerek duruyor.** İlk hesapta 9 saniyeye
indirilmişti; sayılar yeniden yapılınca 9 sn ile kalkış/sn'nin
*düşmediği*, ~%10 **arttığı** çıktı — çünkü ilk hesap "eski: jest
başına 4 kalkış" varsaymıştı, oysa kendiliğinden seçilen üç tekerlekli
jestin ortalaması 2,67'ydi. Bir güvenlik sınırı ölçülmemiş bir
gerekçeyle gevşetilmez.

Sayılar tablodan hesap (boşluk + kalan bekleme ortalaması 2,6 sn +
(kura−1) × 5 sn), gerçek kartta ölçülmedi. Ölçülmesi gereken şey bu
sayılar değil, **sürünmenin kendisi** — aşağıdaki yöntem.

Konuşma **başında** tekerlek yok, bilerek: her cümlenin başında dönmek
hem sıkıcı hem gereksiz motor kalkışı olurdu.

#### 🔴 Uzuv kipleri — tekerlekler ve kollar ayrı ayrı

Kullanıcının isteği (06.09.2026): *"DC motorların sesli komutlar dahil
tamamen kapatacak bir ayar… ayrı şekilde kollar yani servolar için de
koy. Belki çocuk motorların veya servoların konuşma boyunca hiç hareket
etmesini istemez."*

**Açma-kapama yetmiyordu, çünkü üç hâl var ve üçü de isteniyor:**

| Kip | Pati kendi | Sesli komut | Panel | Kullanım |
|---|---|---|---|---|
| `KIP_ACIK` **(varsayılan)** | ✓ | ✓ | ✓ | normal |
| `KIP_KUMANDA` | — | — | ✓ | "kendi kendine kıpırdamasın ama çocuk oynatabilsin" |
| `KIP_KAPALI` | — | — | — | gürültü istemiyorum / pil / Pati rafta |

*Kapalı* ile *sadece kumandadan* arasındaki fark, çocuğun elinden
kumandayı alıp almamak — iki ayrı açma-kapama ile anlatılamazdı.

**Sesli komut `KIP_KUMANDA`'da çalışmıyor**, çünkü üstünde parmak yok.
Bu, ölü adam zamanlayıcısının gerekçesinin aynısı: sürekli onay yoksa
bu Pati'nin kendi hareketidir.

⚠️ **İstek ile KAYNAĞI tek atomikte taşınıyor** (`no + kaynak * 256`).
İki ayrı değişken olsaydı panel bir jest yazarken sohbet görevi kaynağı
değiştirebilir ve Pati'nin kendi isteği "kumandadan geldi" diye
geçerdi — yani ebeveynin kipi sessizce delinirdi.

**Kollar `KIP_KAPALI` iken dinlenmeye inip susuyor.** Olduğu yerde
dondurmak yanlış olurdu: havada kalmış bir kol "bozuldu" görünür.
Dinlenme açısına inip orada darbe kesiliyor, yani servo sessiz ve
akımsız.

#### Tek boğaz

Pati'nin kendi kararıyla dönen tekerlek **tek bir yerden** geçiyor
(`pati_beden.cpp`, "OZERK HAREKET — TEK BOGAZ"). Özerk jest, sesli
komut, panelin jest düğmesi — hepsi. Üç kural, sırasıyla:

1. **Çocuğun parmağı her şeyi yener.** Joystick'ten komut geldiyse akan
   jest iptal ve tekerlek onun.
2. **Kip izin vermiyorsa tekerlek yok** — isteğin kaynağına bakarak.
3. **Hız tavanı özerk harekete de uygulanıyor.** Kaydırıcıyı kısan
   ebeveyn Pati'nin kendi hareketlerini de kısmış oluyor; iki ayrı sayı
   olsaydı panel yalan söylerdi.

#### Kol ile tekerlek hiç aynı anda hareket etmiyor

Üç ayrı önlem, hepsi aynı ölçülmüş sebep için (aynı AA hattı, motor
kalkışında gerilim çöküntüsü):

- Jest tablosu aynı karede ikisini birden komut edemiyor (kural 1)
- Tekerlek dönerken **servo darbesi kesiliyor** — hedefe yeni varmış
  bir servo 250 ms daha tutma torku uyguluyor ve asıl akım orada
- Tekerlek dönerken **kol duruyor** (hedefini unutmadan; dönüş bitince
  kaldığı yerden devam ediyor)

⚠️ **Tekerlek karesi kolun varmasını beklemiyor.** Beklemek tekerleği
kola bağlardı: kol yolda takılırsa kare hiç ilerlemez ve tekerlek
**sınırsız** dönerdi. Bir motorun durma koşulu asla başka bir şeyin
varması olmamalı — yer değiştirme sıfır olsa bile.

### 🔴 Dönüş yönü ters çıktı — sebebi ayırt edilmedi

06.09.2026, gerçek kartta: çocuk çubuğu **sağa** itince Pati **sola**
dönüyordu. İleri ve geri doğruydu — kullanıcı Pati'yi hem yüzü hem
sırtı dönükken denedi, ikisinde de Pati kendi ileri yönüne gitti. Yani
iki motorun ileri yönü doğru; ters olan yalnızca dönüş.

⚠️ **İki sebep de bu belirtiyi birebir veriyor ve hangisi olduğu
ölçülmedi:**

| | Ne olurdu | Neden ileri/geri etkilenmez |
|---|---|---|
| **(a) Kablo** | Sol ve sağ motor L9110'un A/B kanallarına ters bağlanmış | İkisi de aynı yöne gider, hangisinin "sol" sayıldığı fark etmez |
| **(b) Ayna** | Pati'nin yüzü çocuğa dönükse robotun kendi "sağı" çocuğun "solu"dur | Yön değişmiyor, sadece bakış açısı |

**Nasıl ayırt edilir:** Pati'nin **sırtı** çocuğa dönükken sür.
(a) ise o yönde de ters görünür; (b) ise doğru görünür.

Düzeltme iki hâlde de aynı olduğu için **karıştırmada** duruyor
(`SURUS_X_YONU = -1`): kumandanın hissini belirleyen yer orası ve
konak testinin koruyabildiği tek yer orası. Pin haritasına koymak,
ayırt edilmemiş bir iddiayı donanım belgesine yazmak olurdu —
`pati_pinler.h`'de yalnızca ölçülmüş şeyler var.

🔴 **(a) olduğu bir gün kanıtlanırsa düzeltme pin haritasına
taşınmalı.** O zaman `/api/durum`'daki `beden.sol` fiziksel **sağ**
tekerleği anlatıyor demektir ve `TESHIS.md` insanları o alana bakmaya
gönderiyor — bir arıza ararken saatler yer.

`jest_donus` de aynı işareti kullanıyor, yani jest tablosundaki
"sağa dön" ile kumandanın "sağa dön"ü aynı yön. Jestlerin net dönüşü
sıfır olduğu için ayrışsalar kimse fark etmezdi; kod okuyanı yanlış
bilgilendirirdi.

### 🔴 Pati bedeninin farkında — dört ayrı hâl

Bu bir süs değil, **ölçülmüş bir hatadan çıktı.** Gerçek kullanımda
çocuk *"kolunu kaldır"* dedi ve Pati *"benim kolum yok ki"* dedi.
Yanlıştı: Pati'nin takılıp çıkarılabilen bir gövdesi **var**, o an
takılı değildi.

Modelin bunu kendiliğinden bilmesi mümkün değildi. Ana promptta
*"Kucucuk bir robotsun. Gozlerin ekranda"* yazıyor ve model oradan
**doğru** bir çıkarım yapıyor. Eksik olan bilgi, promptta olmayan bilgi.

Ana prompta dokunulmadı — o Aşama 1'de ölçüldü (5412 karakter, uyum
%9 → %86) ve değişirse sayılar karşılaştırılamaz olur. Bunun yerine
`yuz.PROMPT_EKI`'nin deseni izlendi: duruma göre **ek**.

| Durum | Gönderilen | Pati ne diyor |
|---|---|---|
| Beden takılı | `BEDEN_PROMPT_EKI` + araç şemasında `hareket` alanı | "Baksana, kaldırdım!" |
| Beden yok | `BEDENSIZ_PROMPT_EKI`, `hareket` alanı **şemada hiç yok** | "Şu an bedenim takılı değil! Takarsan kolumu kaldırabilirim. Şimdilik sadece gözlerimle anlatıyorum." |
| Az önce takıldı | yukarıdakine + `BEDEN_YENI_EKI` (bir kez) | "Bedenim geldi! Bak, kolumu kaldırabiliyorum!" |
| Tekerlekler Pati'ye kapalı | yukarıdakine + `BEDEN_TEKERLEK_KAPALI_EKI` | "Tekerleklerim şu an kapalı ama sana kollarımla dans edeyim!" |
| Kollar Pati'ye kapalı | yukarıdakine + `BEDEN_KOL_KAPALI_EKI` | "Kollarım şu an kapalı ama sana dönerek sevincimi gösterebilirim!" |
| **İkisi de kapalı** | `BEDEN_HAREKETSIZ_EKI`, `hareket` alanı **şemada yok** | "Kollarım ve tekerleklerim şu an kapalı. Annene sorarsan açabilir!" |

⚠️ İkisi de kapalıyken söylenen şey **bedensiz hâlden farklı**: kolu
*var*, sadece kapalı. Aynı metni kullanmak, ebeveyni olmayan bir
kabloyu aramaya gönderirdi.

⚠️ **"Az önce takıldı" eskiyorsa düşürülüyor.** Oturum tazelemesi ilk
doğal boşlukta oluyor; o boşluk gecikirse "az önce" yalan olurdu —
çocuk bedeni çok önce takmış, Pati bir anda sevinmeye başlamış
görünürdü. 90 saniyeden eskiyse bayrak sessizce düşüyor
(`beden_yeni_takildi_al`).

⚠️ **Tekerlek anahtarı MODELE de söyleniyor, sadece motora değil.**
Söylenmezse Pati "dans ediyorum!" der, tekerlekler dönmez ve çocuk
robotun bozulduğunu düşünür. Bu yüzden `ayar_beden_hareket_yaz` oturum
tazelemesi istiyor — tekerlek tarafı anında geçerli, model tarafı tur
sonunda.

**İki listenin ayrışması sessiz bir hata olurdu:** prompt "şunları
seçme" derken `HAREKET_TEKERLEKLI`'yi sayıyor, cihaz ise jest
tablosunun `teker_var` alanına bakıyor. Konak testi ikisini
karşılaştırıyor (§7).

#### 🔴 Kolun mekanik aralığı

Kolların ucuna gerçek kol takılınca ikisi aynı yerlere gidemiyor
(09.09.2026, kullanıcının ölçümü):

| Kol | Aralık | Neden |
|---|---|---|
| **Sol** | %10 – %70 | aşağıda **tekerleğe**, yukarıda **üstteki kabloya** çarpıyor |
| **Sağ** | %0 – %100 | önünde bir şey yok |

Aşılırsa kol bir yere dayanır, servo dönmeye çalışıp durur, ısınır ve
akım çekmeye devam eder. **Belirtisi sürekli bir vızıltıdır** ve kimse
onu bir sınır hatası diye okumaz.

Sınır **yüzdeye** uygulanıyor, açıya değil — jest tablosu da panel de
yüzde konuşuyor (aynı gerekçe `KOL_SAG_AYNA`'da da var). Açıya
uygulansaydı aynalanmış sağ kolda ters ucu kırpardı.

**Kol hedefi tek bir yerden yazılıyor** (`kol_hedef_yaz`). Hedefi yazan
beş ayrı yer var — panel düğmeleri, jest kareleri, konuşma sonu, beden
takılması, kol kipinin kapatılması — ve kırpmayı her birine ayrı
koymak birini unutmaya davetiye olurdu. Unutulan yer kolu bir kez fazla
gönderip servoyu bitirebilir.

⚠️ **Kırpma yazarken yapılıyor, okurken değil.** Jest ilerletme "kol
hedefe vardı mı" diye aynı değeri okuyor; kırpma okuma tarafında
olsaydı hedef ile gerçek konum hiçbir zaman eşitlenmez ve jest hiç
ilerlemezdi.

Jestler sınırı deliyor mu? Hayır — konak testi tabloyu tarayıp
bakıyor. `iki_kol` %95 istiyor, sol kolda %70'e kırpılıyor: iki kol
asimetrik kalkıyor ama hiçbir şeye çarpmıyor. `selam` zaten sağ kolla
yapılıyor.

🔴 **Bu dört sayı `ayar_sifirla()` ile SİLİNMİYOR.** Ayrı flash
bölümünde (`anahtar`) duruyorlar — `partitions.csv` o bölümü tam bu iş
için tanımlamış. Kullanıcının gerekçesi: *"tekrar ayarlanması
unutulursa bir yerlere çarpıp servo bozulabilir."*

Panelde dört çubuk var ve **çubuğu bırakınca kol oraya gidiyor**, yani
ebeveyn çarpıp çarpmadığını görerek ayarlıyor. İki çubuk **tek
istekte** gidiyor (`kol_sol_araligi` / `kol_sag_araligi`): ayrı ayrı
gönderilseydi arada `en_az > en_cok` olan bir an oluşur ve kol o an
yanlış yere giderdi.

#### Tek kol jestleri

`sag_kol` ve `sol_kol` doğrudan *"kolunu kaldır"* için var: kaldırıp
**900 ms tutuyor**, sonra indiriyor. Tutmanın bedeli yok — servo
hedefe varınca darbe kesiliyor ve hafif plastik kol kendi ağırlığıyla
düşmüyor.

Sıfırıncı kare öteki kolu açıkça **indiriyor** (`-1` değil `0`):
"tek kolunu kaldır" denince önceki jestten kalan diğer kolun havada
kalması, hareketi okunmaz yapardı.

⚠️ Sağ/sol **Pati'nin kendi tarafı**, çocuğun değil. Karşılıklı duran
iki kişide bu her zaman böyle.

### Sesli komut — asıl risk yanlış anlama değil

Çocuk "dans et" deyince Pati dans ediyor. Bunu model, zaten açık olan
`yuz_ifadesi` aracına eklenen `hareket` alanıyla istiyor.

**İkinci bir araç eklenmedi ve bu ölçüme dayanıyor:** araç çağrısı
medyanı ~682 ms artırıyor ve cihazda araçlar **sıralı** çalışıyor
(istemci `NON_BLOCKING` alanını setup'a yazmıyor). İkinci bir araç,
modele durup beklemek için ikinci bir sebep olurdu; oysa model bu aracı
duygusu değiştiğinde nasılsa çağırıyor.

Alan ve bedeni anlatan prompt eki **yalnızca beden takılıyken**
gönderiliyor — olmayan bir bedeni anlatmak, Pati'ye yapamayacağı bir
şey vaat ettirirdi. Beden takılıp çıkarıldığında beden katmanı oturum
tazelemesi istiyor (`ayar_yenileme_iste`), yani karar bayatlamıyor.

⚠️ **"Nasılsın" deyince ileri gider mi?** Sorunun kendisi yanlış yerde
duruyor. Yanlış anlama ihtimali zaten düşük — bu ASR'de kelime yakalama
değil, dil modelinin tanımlı bir aracı seçmesi. Ama önemli olan o
değil: **"ileri git" DOĞRU anlaşılırsa da Pati masadan düşer.** Üstelik
joystick'in aksine sesli komutun üstünde parmak yok, yani ölü adam
zamanlayıcısı onu koruyamaz — onay sürekli değil, tek seferlik.

Bu yüzden çözüm "model daha iyi anlasın" değil, **sözlükte ilerlemenin
hiç olmaması**. Yanlış anlamanın en kötü sonucu: Pati garip bir anda
sevimli bir dönüş yapar.

Pati yürüyemediğini ayrıca **söylüyor**: *"Ben kendim yürüyemem, gözüm
yok, masadan düşerim! Ama telefondaki düğmelerden beni sen
sürebilirsin."* Bu doğru, ve karakterin parçası.

---

## Panel

Kumanda kartı **yalnızca beden takılıyken** görünüyor. Joystick, kol
düğmeleri (her dokunuşta çeyrek adım), hazır jestler, hız sınırı
(varsayılan panelde %50 = cihazda %70) ve **iki kip seçimi**
(Tekerlekler / Kollar, ikisi de varsayılan AÇIK).

**Kapalı uzvun düğmeleri sönüyor**, gizlenmiyor: düğmenin varlığı
seçimi değiştirince ne kazanılacağını gösteriyor. Basıp hiçbir şey
olmaması ise çocuğa düğmenin bozuk olduğunu düşündürürdü — mavi tuş
için de aynı karar verilmişti.

| Kapalı olan | Sönen |
|---|---|
| Tekerlekler | joystick + `data-teker` jest düğmeleri |
| Kollar | kol ▲▼ düğmeleri + kol jestleri |

⚠️ Joystick'te `pointer-events: none` da var. Yalnızca soluklaştırmak
dokunmayı engellemezdi ve çocuk sönük bir çubuğu sürüklemeye
çalışırdı.

`POST /api/beden` — sıcak yol, dokunma sürerken 150 ms'de bir çağrılıyor.
İçinde NVS, I2C ve kilit yok.

```json
{ "x": 40, "y": 80 }          joystick konumu, -100..100
{ "kol_sol": 75 }             kaldırma yüzdesi 0..100
{ "jest": "selam" }           yalnızca kol: dinlen · selam · iki_kol
                              · alkis · dusun
                              tekerlekli:   sevin · titre · hayir
                              · bak_etrafina · dans
```

Karıştırma (`sol = y−x`, `sağ = y+x`) ve hız tavanı **cihazda**. Panel
yalnızca parmağın nerede olduğunu söylüyor. İki sebep: tavan cihazda
dursun (panel gönderse bile aşılamasın), ve karıştırmanın işareti konak
testinde yakalanabilsin — JS'te olsaydı "sola bas, sağa gitsin" hatası
ancak robot masadayken fark edilirdi.

Hız sınırı ve kipler `/api/ayar` üzerinden NVS'e yazılıyor
(`beden_hiz`, `tekerlek`, `kol` — sonraki ikisi 0/1/2).

**Eski anahtarlardan geçiş yazılı.** 3.2.x'te tek bir `hareket`
açma-kapaması vardı; kapalı demek "tekerlek yalnızca joystick'ten
dönsün", yani tam olarak `KIP_KUMANDA`. `tekerlek` anahtarı yoksa ve
`hareket` varsa o eşleme uygulanıyor. Geçiş olmasaydı anahtarı
kapatmış bir ebeveyn güncellemeden sonra Pati'yi yine kıpırdar bulur
ve ayarının sessizce kaybolduğunu fark etmezdi.

⚠️ Her yeni ayar için **yeni NVS anahtarı** kullanılıyor. Aynı adı
yeni bir anlamla kullanmak, eski değeri yeni özelliğin varsayılanı
yapar — yani "varsayılan açık" o cihazda hiç gerçekleşmez.

### 🔴 Hız sınırı: panel 0–100 gösterir, cihaz 40–100 saklar

%40'ın altında tekerlek dönmüyor, yalnızca ötüyor (06.09.2026'da gerçek
kartta ölçüldü). O aralığı kaydırıcıda göstermek, çocuğa **hiçbir şey
yapmayan bir yer** bırakmak olurdu.

Çubuk yine de alışıldık 0–100 görünümünde kalıyor; dönüşüm panelde
(`pati.js` · `gosterilendenGercege`):

| Panelde görünen | Cihazda | |
|---|---|---|
| %0 | %40 | en yavaş çalışan değer |
| **%50** | **%70** | **varsayılan** |
| %100 | %100 | tam güç |

⚠️ **Bedeli: panelde yazan sayı ile motora giden sayı aynı değil.**
Bir arıza ararken karıştırmamak için iki önlem var:

- Panel gerçek değeri de küçük puntoyla yazıyor (*"Motora giden: %70"*)
- `/api/durum` → `kumanda.hiz` **her zaman gerçek değeri** döndürüyor,
  gösterileni değil

Sınırlar tek kaynakta: `pati_beden_matematik.hpp` → `HIZ_TAVAN_EN_AZ` /
`HIZ_TAVAN_EN_COK`. Karıştırma da, ayar katmanı da aynı sabitleri
kullanıyor; konak testi alt sınırın altına düşülemediğini koruyor.

---

## Devreye alma — sıra önemli

### A. Açılış seğirmesi testi — **masada değil, elde**

Beden bağlı, **Pati havada, tekerlekler serbest**.

🔴 **SIRA ÖNEMLİ — önce Stick, sonra AA:**

1. AA anahtarı **kapalı**
2. StickS3'ü aç
3. **2-3 saniye bekle**
4. AA anahtarını aç

Bu sıra, aşağıdaki "açılış seğirmesi" penceresini **tamamen kapatıyor**:
yazılım pinleri kurmadan sürücüye hiç güç gitmiyor. Kablolama
diyagramından alındı; önceki hali (AA açıkken Stick'i çalıştır) o
pencereyi açık bırakıyordu.

> **Ne arıyoruz:** açılışın ilk yarım saniyesinde tekerlekler dönüyor mu?
> Yazılım pinleri kurana kadar ESP32 çıkışları havada kalıyor ve
> L9110'un girişleri belirsiz. `beden_baslat()` `app_main`'in en
> başında, `guc_baslat()`'ın hemen ardında — pencere önyükleyici
> süresine inmiş durumda ama sıfır değil.
>
> **Dönerse:** iki adet 10 kΩ direnç, her motor girişinden toprağa.
> **Dönmezse:** modülün kendi direnç ağı işi görüyor, parça gerekmiyor.

**Ölçüm sonucu: _______________**

### B. Algılama

Stick'i takıp çıkar. Seri portta `BEDEN TAKILDI` / `beden cikarildi`,
panelde kumanda kartının gelip gitmesi. Hızlı takıp çıkarmada seğiriyor
mu (1 saniyelik kararlılık penceresi yeterli mi).

**Ölçüm sonucu: _______________**

### C. Kollar

Jest düğmeleri, konuşurken kendiliğinden hareket, darbe kesme.

- Jest sırasında `gozler_kare_us` değişiyor mu, atlanan kare çıkıyor mu?
  (Sağlıklı: kare 24–30 ms, bütçe 50 ms — `TESHIS.md`)
- Kol durduğunda servo gerçekten susuyor mu?
- Kol ters yöne gidiyorsa: `pati_beden_matematik.hpp` → `KOL_SAG_AYNA`
- Kol yeterince kalkmıyor / dayanıyorsa: `KOL_DINLENME_DERECE`,
  `KOL_TAVAN_DERECE`

**Ölçüm sonucu: _______________**

### D. Tekerlekler ve kumanda

#### ✅ 06.09.2026 — PWM frekansı: 20 kHz çalışmıyor, 5 kHz'e indi

İlk denemede **servolar oynadı, motorlar hiç oynamadı.** Belirti tam bir
kablo hatası gibi görünüyordu; ölçüm başka yeri gösterdi.

Ölçüm zinciri (beden takılı, tekerlekler sökülü, pil %41):

| Katman | Nasıl bakıldı | Sonuç |
|---|---|---|
| Panel → `/api/beden` | doğrudan POST | ✅ `{"tamam":true}` |
| Karıştırma + hız tavanı | sürerken `/api/durum` → `beden` | ✅ `sol=60 sag=-60` |
| Firmware → LEDC | yukarıdaki sayı zaten oradan geliyor | ✅ |
| %60 duty @ 20 kHz | gözle | ❌ **dönmedi** |
| %100 duty @ 20 kHz | hız sınırı %100 yapılıp | ✅ **döndü** |

🔴 **Ayırt eden şey %100.** Orada duty 1023/1024, yani **anahtarlama
neredeyse hiç yok** — çıkış sürekli DC. Kırpılmış her duty'de L9110'un
kenarları yetişmiyor. Sürücü bipolar, üzerinde ~1 V düşüyor ve rahat
çalıştığı aralık 1–10 kHz.

20 kHz "mikrofon duymasın" diye seçilmişti. Gerekçe doğruydu ama
**öncelik yanlıştı**: motor dönerken TT redüktörünün mekanik sesi PWM
cıvıltısından zaten yüksek, ve motorlar yalnızca çocuk sürerken dönüyor.

⚠️ **Bir daha aynı belirti görülürse sıra şu:** "servolar oynuyor,
motorlar oynamıyor" kabloya baktırıyor. Kabloya bakmadan önce panelden
`beden.sol/sag` oku — orada doğru sayı varsa sorun kabloda **değil**,
sinyalin sürücü çıkışına dönüşmesinde.

#### Ölçülmeyi bekleyenler

- **En düşük dönen duty kaç?** `MOTOR_EN_AZ_DUTY` hâlâ %35 ve **hâlâ bir
  tahmin** — yukarıdaki ölçüm frekansı ölçtü, ölü bölgeyi değil.
  Ölçmek için ek koda gerek yok: **panelin hız sınırı kaydırıcısı**
  joystick sonuna kadar itildiğinde uygulanan duty'nin ta kendisi.
  Tekerlekler **takılı** ve Pati **yerdeyken** (yük gerçekçi olsun)
  %20'den başla, beşer artır; ilk dönen değer ölü bölgedir.
- **L9110 elle dokunulacak kadar soğuk mu?** (5 kHz'de olmalı.)
- **Sürüş sırasında `sohbet_mik_tepe` yükseliyor mu?**
- **Ölü adam çalışıyor mu?** Parmağı joystick'te tutarken telefonun wifi
  bağlantısını kes — Pati 600 ms içinde durmalı.
- ⚠️ **Motor dönerken çökme oluyor mu?** Yukarıdaki testte `guc.cokme`
  26 → 27 oldu. **Tek artış kanıt değil** — Pati pilde zaten kendi
  başına çöküyor (`PIL.md`, pil %41'di). Ama motor akımı ortak topraktan
  dönüyorsa bu gerçek bir etken olabilir. Uzun sürüşte sayacı izle.

---

## 🔴 Motor gürültüsü — belirtisi tanıdık olacak

Motor akımı I2S ve I2C hatlarına biniyor. Belirtileri **`TESHIS.md`'deki
"yanlış kart" tablosunun aynısı**:

- ses cızırdıyor
- ES8311 cevap vermiyor
- M5PM1 NACK veriyor / L3B açılmıyor
- ekran siyah kalıyor

**Motor eklendikten sonra bu belirtiler görülürse önce gürültüye
bakılacak, yazılıma değil.** Çare: 100 nF seramikleri motor uçlarına
takmak (üç tane: uçlar arası, ve her uçtan gövdeye). Aldığın
kondansatörler tam bunun için.

---

## Sıradaki: bedeni Pati'yi de beslesin

`PIL.md`'deki brownout hâlâ çözülmedi — 250 mAh'lik hücre Pati konuşmaya
başlarken çöküyor. Bedende **4 AA pil** var.

M5Stack'in belgesi: Hat2-Bus'ın **EXT_5V** pini varsayılan olarak
**giriş** kipinde ve oradan 5 V beslemek destekleniyor. 6 V → 5 V küçük
bir çevirici (MP1584 / LM2596 / 5 V UBEC) AA pilden Stick'i besleyebilir.

Olacaklar, hepsi kendiliğinden:

- brownout biter — akım artık AA'dan geliyor
- `guc_kaynak()` "USB" görür → ses tavanı ve göz kare hızı kendiliğinden
  yükselir (kod zaten böyle yazılmış, hiçbir şey değişmiyor)
- lityum hücre boşalmak yerine şarj olur

⚠️ Ama bu yukarıdaki **tek pazarlıksız kuralı deler**: o zaman
konnektörde gerçekten bir güç kablosu olur. Ayrı bir aşama, ayrı bir
karar; o kablo diğer yedisinden fiziksel olarak ayrılmalı (farklı renk,
farklı konnektör).

---

## ⚠️ AÇIK İŞ — servolar

06.09.2026 akşamı: servolar önce çalışıyordu, **iki motoru %100'de
5 saniye döndüren testten sonra** oynamaz oldu. Motorlar aynı anda
çalışmaya devam ediyor.

### Ölçülenler

| Gözlem | Ne kanıtlıyor |
|---|---|
| Motorlar panelden dönüyor *(o an)* | AA hattı o anda amper verebiliyordu — **kalıcı sonuç DEĞİL, aşağıya bak** |
| Açılışta **sağ** servo oynadı | Servolara gerilim **ve** sinyal ulaşıyor; pin 9 sağlam; sağ servo canlı |
| Cihaz komutu uyguluyor (`beden.kol_*` değişiyor) | Panel → firmware → LEDC yolu sağlam |
| Servo ve motor kanalları aynı görevde, aynı kurulumda | Motorlar çalışıyorsa servo darbeleri de üretiliyor |

🔴 **Yazılım elendi, tahminle değil zaman çizelgesiyle:** servolar 3.1.0
üzerinde, firmware'de hiçbir şey değişmeden öldü (değişen tek şey
`beden_hiz` ayarıydı ve o yalnızca motor duty'sine giriyor). Sonrasında
cihaz defalarca yeniden başladı; `beden_baslat()` her açılışta LEDC'yi
sıfırdan kuruyor ve **servo durumu NVS'e hiç yazılmıyor.** Yeniden
başlatmayı atlatan bir yazılım kilitlenmesi mümkün değil.

Zamanlayıcı çakışması da yok: arka ışık TIMER_1, kollar TIMER_2,
motorlar TIMER_3.

### 🔴 En muhtemel sebep: BESLEME ARALIKLI

Aynı akşam biraz sonra **motorlar da durdu** — dönmek yerine PWM
frekansında ötmeye başladılar. Sonra yine döndüler, sonra yine öttüler.

Bu, tek tek bakıldığında yanıltıcı olan bütün gözlemleri tek bir şeyle
açıklıyor: **AA hattı aralıklı.** Dinlenince toparlıyor, yük binince
saniyeler içinde çöküyor.

⚠️ **BURADA BİR YANLIŞ TEŞHİS YAPILDI ve tekrar edilebilir:** "motorlar
dönüyor, demek hat sağlam, pil elendi" denildi. O an doğruydu ama
**kalıcı sonuç çıkarmak yanlıştı.** Aralıklı bir arızada tek bir başarılı
ölçüm hiçbir şeyi elemiyor — arıza zaten aralıklarla kayboluyor.
Doğrusu: aynı testi dinlenmiş ve yorulmuş halde tekrarlamak, ya da
multimetreyle **yük altında** ölçmek.

Bitmiş alkalin pilin ders kitabı davranışı bu. Aynı davranışı ısınan
yüksek dirençli bir ek de yapar — ikisi ancak ölçümle ayrılır.

İkinci sebep (elenmedi): bastırmasız hatta motor anahtarlama
sıçramaları. Servolar motorlarla
aynı AA hattında ve **hiçbir bastırma yok** — ne 100 nF, ne büyük
kondansatör. Kondansatörler planda "belirti çıkarsa tak" diye isteğe
bağlı bırakılmıştı; **motorların ilk gerçek denemesinden önce takılmalıydı.**

### Devam edilecek yer

1. Sinyal uçlarını **pin 7 ↔ pin 9** yer değiştir. Arıza takip ederse
   kablo, etmezse o servo gitmiş.
2. Servo güç uçlarını doğrudan **L9110'un `VCC`/`GND`** pinlerine al —
   motorların dönmesi o pinlerde sağlam gerilim olduğunu kanıtlıyor,
   bu hamle şüpheli demeti devre dışı bırakıyor.
3. Orta nokta testi (%40 ↔ %60): uçlara hiç gitmeden. Ortada oynayıp
   uçlarda oynamıyorsa kol **mekanik olarak sıkışıyor** ve
   `KOL_DINLENME_DERECE` / `KOL_TAVAN_DERECE` (20°–150°) daraltılmalı.
   O iki sayı ölçülmedi, seçildi.

### Yeni servo takmadan önce

**İki adet 100 nF, L9110'un yeşil klemensine** — her motorun iki
vidasına birer tane. Lehim gerekmiyor, kondansatörün bacakları motor
kablolarıyla aynı vidaya giriyor. Yoksa aynı şey tekrarlar.

Hattaki gerilim çöküşü ayrı bir iş ve 100 nF onu çözmüyor: AA uçlarına
paralel **470–1000 µF elektrolitik** gerekiyor (henüz alınmadı).

---

## 🔴 Powerbank'li gövde — 12.09.2026

İkinci bir gövde yapıldı. Eskisiyle **aynı**: 2 servo, 2 DC motor, aynı
sürücüler. Tek fark besleme: eski gövde 4'lü kalem pil, yeni gövde
**powerbank** (Thull 5000 mAh).

⚠️ **Eski gövde duruyor ve kullanılıyor.** Çözüm önce panelden açılıp
kapanan bir ayardı; kullanıcı 12.09.2026'da *"panelde olmalarına gerek
yok, varsayılan olarak açık olsunlar"* dedi ve ayar kaldırıldı.
**Hareket artık her gövdede çalışıyor.**

Kalem pilli gövdedeki bedeli küçük ama sıfır değil: 13 saniyede bir
5 puanlık iki kol hareketi, yani hafif bir pil tüketimi ve göze
çarpabilen bir kıpırdanma. Bilinerek kabul edildi. Geri alınacak yer
`pati_beden.cpp`'de tek bir koşul.

### Sorun

Powerbank akım çekilmeyince **15 saniyede** kendini kapatıyor. Bir kere
uyuduğunda kendiliğinden uyanmıyor: kabloyu çıkarıp takmak ya da
powerbank'in düğmesine basmak gerekiyor.

⚠️ **Powerbank her çıkışı AYRI izliyor.** Kullanıcı Type-C'yi Stick'e,
USB-A'yı gövdeye bağlamış. Stick sürekli 100-200 mA çekiyor ama USB-A
kendi başına uyuyor. Yani *"Stick'i powerbank'e bağla"* çözümü zaten
devrede ve yetmiyor.

### Çözüm: 13 saniyede bir minik kol hareketi

Pati boştayken iki kol da **5 puan** oynayıp geri dönüyor. Yön her
seferinde ters çevriliyor, yani kol bulunduğu yerin etrafında salınıp
aynı noktaya dönüyor — zamanla kaymıyor.

Servo hareket ederken **150-250 mA** çekiyor; powerbank'in sayacı
sıfırlanıyor.

⚠️ Hedef yine `kol_hedef_yaz`'dan geçiyor, yani mekanik aralığa
kırpılıyor. **Kol hiçbir şeye çarpamaz.** Aralık ucundaysa o yöndeki
hareket kırpılır; bir sonraki turda ters yöne gideceği için hareket
yine olur.

Kol kipi kapalıysa hareket de gönderilmiyor — "kapalı" kapalı demek.
Tek kapatma yolu bu.

### Denenip ELENEN iki yol

| Deneme | Sonuç |
|---|---|
| **Motor darbesi** — %12 duty, 80 ms, 8 sn arayla | powerbank yine uyudu. %12 duty stall akımını eşiğin üstüne çıkarmaya yetmiyor |
| **Servoları sürekli enerjili bırakmak** | yine uyudu. Kollar hafif, tutma akımı 10-20 mA civarında kalıyor. Ayrıca sürekli vızıltı yapıyor ve mikrofon 10 cm ötede |

### 🔴 Yol üstünde yapılan muhakeme hatası — kayda geçsin

İki başarısız denemeden sonra şöyle denildi: *"powerbank ORTALAMA akıma
bakar, kısa darbe hiçbir zaman yetmez."*

**Yanlıştı.** Kullanıcı itiraz etti ve haklıydı: powerbank'lerin çoğu
ortalama değil **zamanlayıcı** kullanıyor — *"eşiğin altında 15 saniye
geçerse kapan"*. O modelde eşiği aşan **herhangi** bir kısa yük sayacı
sıfırlıyor.

Yani sorun sürenin kısalığı değil, motor darbesinin **gücüydü**. Doğru
teşhis konunca çözüm ilk denemede çalıştı.

**Ders:** bir mekanizmanın nasıl çalıştığı varsayılmadan önce, elde iki
başarısız ölçüm varken bile o ölçümlerin *neyi* elediği ayrı ayrı
sorulmalı. "Süre yetersiz" ile "güç yetersiz" farklı şeyler ve ikisi
aynı belirtiyi veriyordu.

### 🔴 Kol yönü — ikinci gövdede servolar ters takılı

Kullanıcının şikâyeti (12.09.2026): powerbank'li gövdede *"kolunu
kaldır"* deyince kol **aşağı** iniyor. Servolar ters monte edilmiş.

Panelde **"Kol yönünü ters çevir"** anahtarı var, **varsayılan kapalı**
(ilk gövdenin davranışı).

⚠️ **Çevirme MANTIKSAL YÜZDEDE yapılıyor**, açı ya da darbe
genişliğinde değil — `pati_beden.cpp` · `kol_aci()`, tek boğaz.

Sebep önemli: kol aralıkları da yüzde uzayında tanımlı ve
`kol_hedef_yaz` orada kırpıyor. Çevirme çıkış tarafında olsaydı,
**kırpma bir uca bakarken servo öbür uca giderdi** — yani aralık
koruması ters çalışır ve kol tam da çarpmaması gereken yere giderdi.

Böylece yüzde her zaman aynı şeyi anlatıyor (0 = aşağı, 100 = yukarı)
ve fiziksel yön tek satırda dönüyor.

⚠️ `kol_aci()` **bütün** `kol_derece10` çağrılarının yerini aldı. Biri
atlanırsa "hedefe vardı mı" karşılaştırması çevrilmiş değerle
çevrilmemişi kıyaslar ve **jest hiç ilerlemez**.

🔴 **Ayar `ayar_sifirla()` ile SİLİNMİYOR** — kol aralıklarıyla aynı
gerekçe, kullanıcının kendi sözleriyle: *"çocuk fabrika ayarlarına
dön'e basarsa ve yönleri değiştirmeyi unutsa kollar bir yere
çarpabilir."*

İki bağımsız koruma var:

| | |
|---|---|
| `ayar_sifirla()` | adı sayılan anahtarları siliyor; `kol_ters` o listede **yok** |
| Depo | `kalici_sayi_yaz` **ayrı flash bölümüne** yazıyor (`nvs_open_from_partition`) |

⚠️ **Fabrika sıfırlama gerçek kartta ÇALIŞTIRILMADI**, çünkü
`POST /api/fabrika` içinde `ag_unut()` var ve wifi bilgisini siler.
Koruma kod okunarak doğrulandı, ölçümle değil. İkisi de yapısal
olduğu için güvenilir, ama not düşülüyor.

### ⚠️ Kol aralıkları iki gövde arasında PAYLAŞILIYOR

Pati hangi gövdede olduğunu bilmiyor; aralıklar tek kopya ve kalıcı
depoda. İkinci gövdenin mekanik sınırları farklıysa (kol farklı yere
çarpıyorsa) gövde değiştirirken **aralıkların da ayarlanması gerekir.**
Bu ölçülmedi — ikinci gövdede kolun neye çarptığı henüz bakılmadı.

### Panelin kol düğmeleri sınırı aşıyor gösteriyordu — 3.5.15

Kullanıcının bildirdiği kusur (12.09.2026): *"sol için %70 yaptım ama
servo kontrol şeyinde onu 100'e kadar çıkarabiliyorum."*

Panel kendi sayacını **0–100** arasında kırpıyordu, ebeveynin
ayarladığı aralıkta değil:

```js
K.kol[hangi] = Math.max(0, Math.min(100, K.kol[hangi] + yon * 25));
```

Cihaz doğru davranıyordu — `kol_hedef_yaz` 70'e kırpıyor ve kol 70'te
duruyor. **Yanlış olan gösterge**: panel "%100" yazıyordu.

⚠️ Bedeli görünenden büyük: ebeveyn ayarladığı sınırı paneldeki sayıya
bakarak **doğrulayamıyordu**. "Sınır çalışmıyor" diye okunabilirdi ve o
yanlış okuma, aralığı hiç kullanmamaya götürürdü — yani servoyu
koruyan tek şeyi.

Düzeltme `kolSinirla()`: sınırları çubuklardan okuyor (onlar da
cihazdan geliyor), yani tek kaynak kalıyor. "Dinlen" jesti de artık
0'a değil, ayarlanan tabana iniyor.

🔴 **Asıl koruma hâlâ cihazda** (`kol_hedef_yaz`). Paneldeki kırpma
onun yerine geçmiyor, yalnızca panelin doğru söylemesini sağlıyor.

**Aynı tuzak bu depoda üçüncü kez:** ses tavanı (3.5.5), cevap hızı
kutusu (3.5.10), şimdi kol düğmeleri. Hepsinin dersi aynı — *bir sınırı
iki yerde tutuyorsan, ayrıştıklarında kimse fark etmez.*

### Dinlenme konumu = aralığın ortası — 3.5.16

Kullanıcının isteği (12.09.2026): *"dinlenme derecesi min ile maks
toplamı bölü 2 olsun — çocuk sol kolu 0-70 ayarlarsa dinlenme 35, sağ
0-100 ise 50 olacak."*

Öncesinde dinlenme sabit `%0` idi ve `kol_hedef_yaz` onu aralığın **alt
ucuna** kırpıyordu. Yani dinlenme ile mekanik alt sınır aynı şeydi ve
birbirinden ayrılamıyordu.

Orta nokta ayrıca **en güvenli yer**: kol iki uçta da bir şeye
değebiliyor (sol kol aşağıda tekerleğe, yukarıda kabloya), ortada
ikisinden de en uzakta duruyor.

Tek kaynak `pati_beden.cpp` · `kol_dinlenme()`.

⚠️ **Jest tablosundaki `0` artık "dinlenme" demek**, "en aşağı" değil.
Her jestin son karesi `{0, 0}` ve anlamı "kolları bırak"; `JEST_DINLEN`
zaten tek kare: `{0, 0, 0, 0}`. Bağlanmasaydı tutarsızlık çıkardı —
konuşma sonunda kol ortaya, jest sonunda alt uca giderdi.

Tablo **değiştirilmedi**: sabitler konak testinin taradığı veri ve
orada `0` hâlâ `0`. Çeviri yalnızca uygulama anında.

### 🔴 ÇÖZÜLEMEYEN: Pati kapalıyken servo oynuyor

Kullanıcının gözlemi (12.09.2026): StickS3 tamamen kapalıyken ama gövde
beslemedeyken servolardan biri aralığın dışına (~%-20) gidip hareket
ediyor.

**Sebep:** Pati kapanınca servo sinyal pinleri (`GPIO1`, `GPIO8`)
havada kalıyor. Servo besleme almaya devam ediyor ve havadaki hat
gürültü topluyor; servo bunu geçerli darbe sanıp rastgele bir yere
gidiyor. Oraya dayanırsa ısınır ve yanar.

| Durum | Yazılımla çözülür mü |
|---|---|
| **Derin uyku** (mavi tuş) | **evet** — çip beslemede, `gpio_hold_en` pinleri aşağıda tutabilir |
| **Tam kapatma** (yan düğme) | **hayır** — çip beslemesiz, hiçbir yazılım çalışmıyor |

🔴 **Tam kapatma için tek çözüm donanım**: her servo sinyal hattından
toprağa 10 kΩ. Hat aşağıda kalır, servo geçerli darbe görmez, sessizce
gevşer. Pati açıkken etkisi yok (0,3 mA).

⚠️ **Kullanıcı direnç eklemek istemiyor** (12.09.2026) ve yazılımla
çözülemediği için **bu sorun açık bırakıldı.** Gövde beslemesini Pati
kapalıyken açık bırakmamak tek pratik önlem.

Derin uyku tarafı yapılmadı: kullanıcının tarif ettiği durum tam
kapatma ve o yol zaten kapalı. Yapılacaksa dikkat — uyanışta
`gpio_hold_dis()` unutulursa LEDC pinleri süremez ve **gövde sessizce
ölür.**

---

## ✅ İleri kayma — ÇÖZÜLDÜ (13.09.2026, mekanik)

**Kullanıcı ön tekerlekleri dönebilen (caster / "sarhoş") tekerlekle
değiştirdi ve kayma bitti.**

🔴 **Bu aynı zamanda teşhisin doğrulanması.** Sebep aşağıda fotoğraftan
çıkarılmıştı: sabit akslı ön tekerlekler gövdeyi bir rayın üstüne
koyuyor — ileri-geri serbest, dönmeye karşı katı — ve dönüşe
çevrilemeyen kuvvet direnç görmediği tek eksene kaçıyor. Dönebilen bir
tekerlek o rayı ortadan kaldırıyor.

⚠️ **Yazılımın yapamayacağı şey gerçekten yapılamazdı** ve bu bölümün
asıl değeri orada: üç sürüm boyunca jest tablosu küçültülüp büyütüldü,
hiçbiri kaymayı değiştirmedi. Doğru teşhis mekaniğe yol gösterdi;
yazılımda aranmaya devam edilse hâlâ açık olurdu.

**Sonucu:** tekerlek jestlerinin sıklığı 3.5.25'te rahatça artırıldı
(`TEKER_KALKIS_ARA_US`). Boşluk yine de sıfırlanmadı — Pati'de uçurum
sensörü yok ve sürekli kıpırdayan bir robot huzursuz görünüyor.

Aşağıdaki bölüm teşhisin nasıl yapıldığını tutuyor; benzer bir belirti
çıkarsa yöntem hâlâ geçerli.

---

## 🔴 İleri kayma — "dans et" ve özellikle "kıkırda" (12.09.2026)

Kullanıcının şikâyeti: *"eski patide yoktu ama bu pati örneğin dans et
de biraz ileri gidiyor (özellikle kıkırdada), olduğu yerde kalmıyor."*
İkinci (powerbank'li) gövdede, tekerlekler de farklı.

### Neyin elendiği — sırayla

| Şüpheli | Sonuç |
|---|---|
| Jest tablosunun net dönüşü sıfır değil | **elendi** — konak testi her jestte `net_donus == 0` sayıyor, beşi de sıfır |
| `jest_donus` iki tekerleğe eşit dağıtmıyor | **elendi** — test her girdide `sol + sag == 0` tarıyor |
| `motor_rampa` bir yönde farklı davranıyor | **elendi** — `yavasliyor` kararı iki işaret için simetrik, test ±'da aynı |
| `motor_duty` işareti kaybediyor ama büyüklüğü değil | **elendi** — test `motor_duty(-h) == motor_duty(h)` |
| Bir motor diğerinden güçlü | **elendi, ama düşünmeyi gerektiriyor** — aşağıda |

**Bir motorun diğerinden güçlü olması kaymaya sebep olamaz**, çünkü her
jest yönü değiştiriyor ve bu, her motorun eşit süre ileri ve geri
gitmesi demek. A karesinde sol ileri/sağ geri, B karesinde tersi;
motorlar arası fark iki karede ters işaretle çıkıp **kendiliğinden
sadeleşiyor**. Tablodaki "net dönüş sıfır" kuralı bunu zaten garanti
ediyor.

Geriye **tek bir açıklama** kalıyor: kayma, `teker`'in işaretinden
bağımsız. Yani gövde **ileri yöne geri yönden daha kolay kayıyor** —
motorların değil, **şasinin** bir özelliği. Yeni gövdede tekerlekler ve
muhtemelen destek noktası değiştiği için eski gövdede görünmüyordu.

🔴 **Bunun sonucu önemli: jest tablosunun elindeki tek serbestlik
(`teker`'in işareti) bu kaymayı iptal edemez.** Yazılım kaymayı
*sıfırlayamaz*, yalnızca **azaltabilir**.

### Kaymanın nerede oluştuğu

Her tekerlek karesi motor DURURKEN başlıyor, yani her kare bir **kalkış
darbesi** (%85, 180 ms) demek. Darbe bitince rampa tablodaki değere
iniyor — `MOTOR_INIS_ADIM` 15/tik ve tik 20 ms:

| `teker` | hız tavanı | hedef | iniş |
|---|---|---|---|
| 60 | %100 | %60 | 40 ms |
| 60 | %70 (varsayılan) | %42 | 60 ms |
| 60 | %40 (en düşük) | %24 | 100 ms |

Yani bir karenin **ilk 220–280 ms'si** darbe ve iniştir; üst uç,
ebeveyn hız kaydırıcısını en dibe çektiğinde görülüyor. Kural **300 ms**
çünkü en kötü hâl 280 ve arada pay kalmalı.

Eski kareler 120–220 ms'ydi: **hiçbiri o eşiği görmüyordu.** Robot daha
dönmeye başlamadan kare bitiyor, geriye yalnızca darbenin sarsıntısı
kalıyor — ve jest başına dört kare, dört sarsıntı.

Bu, kullanıcının *"özellikle kıkırdada"* gözlemiyle birebir uyuşuyor:
`titre`'nin kareleri 120 ms ile tablonun **en kısası**ydı, yani dönüş
oranı en düşük, sarsıntı oranı en yüksek jest oydu.

### Yapılan

1. **Her tekerlek karesi ≥ 300 ms** (fiilen 320–360 ms). Karenin son
   bölümünde artık gerçek dönüş var, üstelik tablodaki sayı ilk kez
   motora ulaşıyor. ⚠️ `hayir`'in 200–240 ms'lik kareleri bu kuralın
   altında kalıyor — bilerek, çünkü orada salınım sayısı anlamın
   kendisi.
2. **Jest başına kalkış 4 → 2** (`hayir` hariç). Toplam dönüş süresi
   neredeyse aynı kaldı, sarsıntı sayısı yarıya indi.
3. Boşalan görünürlük bütçesi **sıklığa** gitti (kura 1/3 → 1/2; 12
   saniyelik boşluk **değişmedi**), ama dakikadaki kalkış sayısı yine
   de biraz düştü.

### 🔴 Ölçülecek — tahmin değil

Yukarıdaki teşhis **bir hipotez**: "kayma kalkış başına oluşuyor".
Değişiklik onu sınanabilir yapıyor, çünkü `dans`'ın toplam dönüş süresi
değişmedi (720 ms) ama kalkış sayısı yarıya indi.

| Gözlem | Ne demek |
|---|---|
| `dans`'ın kayması **kabaca yarıya** indi | hipotez doğru, kayma kalkış başına |
| `dans`'ın kayması **değişmedi** | kayma dönüş *süresine* bağlı — çözüm burada değil, toplam süreyi kısaltmak gerekir |
| Kayma **arttı** | uzun karede sürekli dönüş de kaydırıyor; kareler kısaltılmalı ve kayma kaçınılmaz demektir |

**Nasıl ölçülür** — ek koda gerek yok: Pati'yi düz bir masada bir
bant çizgisinin üstüne koy, aynı jesti panelden **beş kez** çalıştır,
çizgiye olan mesafeyi ölç. Beş jest sonunda kaç mm ilerlediği tek
sayıdır ve iki sürüm arasında karşılaştırılabilir.

⚠️ Eski değerler geri gerekirse: kareler 120–220 ms, `TEKER_KURA = 3`,
`TEKER_ARA_EN_AZ_US = 12 sn`.

### Yazılımın yapamayacağı

Kaymayı gerçekten **sıfırlamak** için Pati'nin dönüşe bir miktar geri
hareketi karıştırması gerekirdi — yani `sol + sag != 0`. **Bu yapılamaz
ve yapılmayacak:** o eşitlik Pati'nin masadan düşmemesinin tek yapısal
garantisi ve konak testi her girdide tarıyor. Ölçülmemiş bir telafi
sayısı uğruna o garantiyi delmek, kaymadan çok daha pahalı bir hata
olur.

### 🔴 13.09.2026 — fotoğraf: gövdede DÖRT tekerlek var

Kullanıcı 3.5.18'de *"hâlen biraz öne doğru kayıyor"* dedi ve gövdenin
fotoğrafını gönderdi. Fotoğraf belgede olmayan bir şey gösterdi:

| | |
|---|---|
| **2 tahrikli** | siyah lastik, sarı göbek — TT redüktörlü motorlar |
| **2 serbest** | beyaz, 3B basılmış, **dişli sırtlı**, sabit akslı |

⚠️ **Serbest tekerlekler döner tabla (caster) DEĞİL** — sabit akslı ve
sırtlı. Bu, kaymanın en güçlü açıklaması:

**Sabit bir tekerlek kendi ekseninde neredeyse dirençsiz yuvarlanır,
yana kaymaya ise direnir.** İki tanesi birden, gövdeyi bir **rayın**
üstüne koymak demek: ileri-geri serbest, dönmeye karşı katı.

Pati yerinde dönerken dört tekerleğin dördü de yana sürtünmek zorunda.
Dönmeye çeviremediği her kuvvet, direnç görmediği tek eksene — **ileri
ya da geriye** — çıkıyor. Yana giden hareket sürtünmeyle hemen sönüyor,
ileri giden hareket ise yuvarlanıp gidiyor.

🔴 **Kullanıcının kendi sorusunun cevabı burada:** *"tekerler eskiye
göre daha kalın ve yol tutuşu daha yüksek, ondan mı?"* — evet, çok
muhtemel. Ama asıl suçlu tahrikli tekerlekler değil, **serbest
olanlar**: tutuş arttıkça yana sürtünme direnci artıyor, yani gövde
dönmeye daha çok direniyor ve artan kuvvet ileri eksene kaçıyor.

#### Üç ölçüm — hiçbiri alet istemiyor

| Deney | Ne gösterir |
|---|---|
| **Elle çevir:** Pati'yi masada tutup yerinde döndürmeye çalış | Direniyor ve öne yürümek istiyorsa sebep gövdenin kendisi, motorlar değil |
| **Kaygan zemin:** "dans et"i cam / kitap kapağı / plastik dosya üstünde çalıştır | Kayma kaybolursa sebep **tutuş** |
| **Sadece serbest tekerleri kaydır:** o ikisinin altına bant/koli bandı şeridi koy, tekrar dene | Kayma azalırsa sebep **serbest tekerlekler** |

Üçüncüsü en ayırt edici olanı, çünkü yalnızca tek bir değişkeni
değiştiriyor.

#### ✅ Mekanik çözüm — UYGULANDI VE İŞE YARADI

Serbest tekerleklerin yerine **dönebilen** bir destek: küçük bir
bilyeli caster, mobilya kaydırıcısı ya da yuvarlak pürüzsüz bir ayak.
Dönemeyen bir tekerlek yerinde dönüşe katılamaz — ne kadar iyi
yapılmış olursa olsun.

**13.09.2026: kullanıcı bunu yaptı ("sarhoş teker") ve kayma bitti.**

#### 🔴 Yazılım önce YANLIŞ değişkeni büyüttü — 3.5.19

Kaymayı sıfırlayamadığı için "hareket/kayma oranını" en büyük yapmaya
çalıştı: aynı dönüş süresi, **yarısı kadar kalkış**. Jest başına hareket
sayısı 4'ten 2'ye indi, kareler uzadı.

**Kullanıcının cevabı bunu eledi** (13.09.2026): *"daha kötü hale mi
getirdin, dans et diyorum 2 tane dc motor hareketi yapıyor, seri değil,
eğlenceli değil, eskiden bu kadar değildi."*

⚠️ **Ders: canlılığın ölçüsü toplam dönüş süresi değil, ayrı ayrı
hareket sayısı.** İzleyici için "dört kere kıpırdadı" ile "iki kere
geniş döndü" aynı şey değil; ikincisi daha cansız — toplam dönüş açısı
daha büyük olsa bile. Sayıyı büyütmek doğruydu, *hangi* sayıyı
büyüteceğim yanlıştı.

#### Yazılım şimdi ne yapıyor — 3.5.21

Dördü birden alınıyor ve bedeli açıkça yazılı:

- Jest başına **4 hareket**, her kare **≥ 280 ms** (darbe bitince gerçek
  dönüş var)
- Kol karesi dönüşlerin arasından çıktı
- `TEKER_ARA_EN_AZ_US` 14 → **10 sn**
- `JEST_TEKER_EN_COK_MS` 900 → **1400**

| | Jest arası | Kalkış/jest | Kalkış/sn |
|---|---|---|---|
| 3.5.16 | ~24,6 sn | 2,67 | 0,108 |
| 3.5.18 | ~19,6 sn | 2,00 | 0,102 |
| 3.5.19 | ~19,4 sn | 2,00 | 0,103 |
| **3.5.21** | **~15,4 sn** | **4,00** | **0,260** |

🔴 **İleri kayma hızı kabaca iki buçuk katına çıkıyor.** Kullanıcı bunu
bilerek istedi ve kendisine sayıyla söylendi. Kaymanın gerçek çözümü
zaten yukarıda: **dönebilen bir destek tekerleği.**

**Geri alma yolu tek satır:** `TEKER_ARA_EN_AZ_US`'u büyüt. Kayma
rahatsız ederse önce oraya bakılacak, jest tablosuna değil — tablo
kullanıcının istediği canlılığı taşıyor.

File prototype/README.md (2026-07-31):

# prototype

Python reference implementation. It runs the same conversation loop as
the firmware, on a PC, using the computer's microphone and speaker:

```
microphone → 16 kHz PCM → WSS → Gemini Live → 24 kHz PCM → speaker
```

No SDK, no browser, no audio processing in between — the transport
matches the device, so a number measured here means something there.

## Why it still exists

It is the behavioural reference for the firmware. The host tests compare
the C++ memory engine against `hafiza.py` check by check; a divergence
means one of the two is wrong. Prompt text and extraction rules are read
from here and generated into C++ headers rather than copied by hand.

The timing instrumentation also lives here. Latency is recorded per
turn, and the median/p90 arithmetic is duplicated on the device and
self-tested at boot so that the two remain comparable.

## Setup

```
python -m venv .venv
.venv/Scripts/python -m pip install -r requirements.txt
```

Then place a Gemini API key in `anahtar.txt`. That file, retained
memory, usage counters and transcripts are excluded from version
control.

## Use

```
python pati.py                              conversation; measurements
                                            written to olcumler/
python pati.py --arayuz --sayfa pati --disa serve the parent panel on
                                            the local network
python testler.py                           359 tests
```

`testler.py` covers the measurement tooling and the memory logic, not
the model. It answers "is this instrument reading correctly", not "is
the robot any good".

## Panel development

`../panel/TELEFONDAN-INCELE.bat` runs the second command above and
prints a LAN address. `../panel/PAYLAS.bat` opens an HTTPS tunnel to
it, which browsers require before granting microphone access.

The panel served here and the panel served by the robot are the same
files.

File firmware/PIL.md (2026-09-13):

# Pil modu — Pati pilde çökmemeli

Bu belge **devam eden bir işin** çalışma notu. `TESHIS.md` çözülmüş
sorunları anlatır; burası henüz çözülmemiş olanı.

---

## Amaç

**Pati pille çalışırken çökmemeli.**

Çocuk Pati'yi çoğunlukla pilde kullanacak. "Şarja tak" bir cevap değil —
çocuğu sürekli kabloya bağlı kalmaya zorlayamayız. Harici besleme
(ileride motorlar için gelecek olan) bu sorunu çözer ama **pil modunu
ortadan kaldırmaz**; ikisi ayrı iş.

Bu işin güncel belirtisi pilde konuşurken reset. Geçmişte USB'de de
ayrı PSRAM/bekçi arızaları görüldü; her reset aynı kök nedene bağlanmaz.

---

## 🔴 Kullanıcının öncelik sırası — pazarlık burada biter

Feda etme sırası, en önemliden en feda edilebilire:

1. **Çökmeme** — her şeyin üstünde
2. **Ses seviyesi** — `SES_PIL_TAVANI` **0.70'te sabit, DAHA AŞAĞI
   İNİLMİYOR.** Kullanıcı bunu iki kez açıkça söyledi. Pilde kısık ses
   gerçek bir kayıp: çocuk duyamıyorsa robot işe yaramıyor.
3. **Ekran parlaklığı** — pilde %35. Gerekirse biraz daha kısılabilir,
   ama önce diğerleri denenmeli.
4. **Gözler** — pilde feda edilebilir tek yer. İfadeler güzel ama
   akıcılık, sohbetin kendisinden önce gelmez.

---

## Belirti

Pilde, Pati **konuşmaya başladığı anda** brownout:

```
00:13:03  ifade=dusunuyor    <- cevap uretiliyor
00:13:05  COKTU
00:13:10  geri geldi -> acilis=brownout
```

Öncesinde pil geriliminde sarkma görülüyor (3816 tabanından 3696'ya).
Sıklık: **20-60 saniyede bir**, pil 3,8-3,9 V civarındayken.

Pati 5 saniyede kendine geliyor — bekçi işini yapıyor. Ama çocuk için
cümle ortasında kaybolmak kabul edilemez.

---

## Ölçülmüş gerçekler

- **Dolu pilde de oluyor.** 4,13 V'tan başlıyor; çökmeler 3,8-3,9 V'ta da,
  4,0 V'ta da oluyor. "Pil bitmiş" değil.
- **İki kart da aynı.** İkinci kart kutudan yeni çıktı, aynı davranıyor.
  Bu, tek karta özgü kusuru daha az olası kılar; ortak tasarım sınırını
  veya yük altında besleme sorununu elemez.
- **Tetikleyici konuşma.** Her çökme `dusunuyor`/`konusuyor` anında.
  Yani amfi + telsiz + PSRAM aynı anda akım çekerken.
- **ESP32 sıcaklığı 55-64 °C ölçüldü.** Bu, PMIC veya regülatörün
  sıcaklığı değildir; onların ısıl korumasını tek başına elemez.
- **Göz çizici en büyük sürekli CPU müşterisi.** Kare başına çizim
  24-30 ms, bütçe 50 ms — bir çekirdeğin yarısından fazlası kesintisiz.
  İşin %85'i şekil rasterlemesinde.

---

## Denenenler

| Deneme | Gerekçe | Sonuç |
|---|---|---|
| Ses 1.00 → 0.70 | amfi akımı azalsın | ❌ çökme sürdü |
| Ekran %100 → %45 | taban akım düşsün, tepeye pay kalsın | ❌ çökme sürdü |
| PSRAM 80 → 40 MHz | veri yolu kilitleniyordu | ✅ ama **başka bir sınıfı** çözdü (bkz. TESHIS.md), brownout'u değil |
| Gözler 20 → 10 fps (pilde) | CPU doluluğu yarıya insin | ✅ **çökme arası ~40 sn → ~4,5 dk** (aşağıda) |
| Gözler konuşurken 10 → 5 fps | konuşma anındaki yük | 05.09: devreye giriş kusuru düzeltildi; kartta yeniden ölçülecek |
| Göz parlama katmanı 3 → 1 (pilde) | çizim maliyetinin **%81'i** bu katmanlarda (ölçülmüş) | 🔄 sınanmadı |
| Ekran %45 → %35 | taban akım | Kodda uygulanıyor; pil etkisi doğrulanmadı |
| Wifi verici 20 → 15 dBm (pilde) | telsiz gönderirken 250-350 mA | ❌ **geri alındı** — menzil çöktü (3/4 → 1/4), "modemin dibinde bile zor çekiyor" |
| Ses tavanı 0.70 → **0.60** | hoparlör yükü | Resetin bittiği doğrulanmadı; 05.09'da güncel 0.70 alt sınırı geri getirildi |
| Flash 80 → 40 MHz | PSRAM'den sonraki ikinci saat | Kodda ve yerel sdkconfig'de 40 MHz; pil etkisi doğrulanmadı |
| Brownout eşiği | eşik gereksiz hassas olabilir | ❌ **çürütüldü** — zaten en toleranslı (aşağıda) |
| Açılışta güç kipinin geç girmesi | 6 sn boyunca tam yük | ✅ kusur, düzeltildi (aşağıda) |

⚠️ İlk ikisi **sağlam akıl yürütmeye** dayanıyordu ve tutmadı. Ders:
akım üzerine akıl yürütmek bu projede işe yaramıyor, çünkü **hiç akım
ölçülmedi.** İşe yarayan iki değişikliğin de mekanizması sayıyla
görülmüştü: PSRAM'de program sayacı, gözlerde kare süresi.

### Göz kare hızı ölçümü — 02.09.2026 akşamı

2. kart, 9 dakika 6 saniye pilde, sallamadan, normal sohbet.

| | Zemin (20 fps) | 10 fps |
|---|---|---|
| Çökme | 20-60 sn'de bir | 2 çökme / 9 dk |
| Dağılım | düzenli | 4 dk 52 sn → 49 sn → **3 dk 19 sn temiz** |
| Pil aralığı | 3,8-4,0 V | **3,83 → 3,68 V** |

Yaklaşık **yedi kat seyrelme**, üstelik zeminden **daha düşük gerilimde**.
Göz yükü gerçek bir etken — bu artık tahmin değil.

**Ama çökme sıfırlanmadı.** Göz yükü tek sebep değil.

İkinci bulgu: çökmeler 3744 ve 3732 mV'ta oldu, ardından **3682 mV'ta
3,5 dakika hiç çökme olmadı.** Yani "pil azaldıkça daha sık çöker"
tek başına doğru değil. Tek ölçüm bunu kesinleştirmiyor; `cokme_mv`
alanı (panel → `guc.cokme_mv`) tam bu soruyu biriktirmek için var.

### Açılış penceresi — bulunmuş ve düzeltilmiş kusur

Aynı kayıtta görüldü:

```
19:16:04  cokme=1  goz_fps=20   <- yeniden basladi, gozler HALA tam hizda
19:16:10  cokme=1  goz_fps=10   <- pil kipi ANCAK simdi girdi
```

Güç kipi ana döngüde uygulanıyordu ve o döngü **wifi bağlanıp ilk Gemini
oturumu açıldıktan sonra** başlıyor. Yani Pati brownout'tan yeni
kalkmışken — pil zaten düşük, telsiz bağlanıyor (en yüksek akım), TLS
el sıkışması CPU yiyor — gözleri de tam hızda çiziyordu. Wifi yavaş
bağlansa bu pencere yirmi saniye olurdu.

Çözüm: ayrı bir **güç gözcüsü görevi** (`app_main.cpp` → `guc_gozcusu`),
gözler açılır açılmaz başlıyor ve hiçbir şey beklemiyor.

---

## 🔴 Brownout eşiği — araştırıldı, ÇÜRÜTÜLDÜ

02.09.2026'da şu hipotez kuruldu: "çökmelerin hepsi brownout diyor,
belki eşik gereğinden hassas ve cihaz aslında çalışabilecekken
resetleniyor."

**Yanlış çıktı.** ESP32-S3'te seviyelerin yönü ESP32'nin **tersi**:

```
LVL_SEL_1 = 3.30 V   (en hassas)
LVL_SEL_3 = 2.98 V
LVL_SEL_4 = 2.84 V
LVL_SEL_7 = 2.44 V   (en toleransli)
```

Kaynak: `esp-idf/components/esp_hw_support/power_supply/port/esp32s3/Kconfig.power`
— forum yorumu değil, IDF'in kendi tanımı. (Bir forumda "level 7 =
2,98 V" yazıyordu ve o ESP32 içindi; ona güvenilseydi eşik yanlış
yönde değiştirilecekti.)

Pati **zaten `LVL_SEL_7`'de**, yani en toleranslı ayarda. Düşürülecek
yer yok.

**Sınır:** 2,44 V seçilen kademenin nominal eşiğidir; rayın gerçek
minimum gerilimi osiloskopla ölçülmedi. Brownout kaydı besleme
düşmesini bildirir. 3,3 V beslemede bu küçük bir dalgalanma değil, ciddi bir
çöküş. Yani sorun ölçüm eşiğinde değil, gerçekten güçte — ve yazılım
tarafında aranacak şey "hangi kod çöktürüyor" değil, **"hangi kod
akım çekiyor"**.

---

## Denenmemiş adaylar

**Wifi verici gücü:** 15 dBm denemesi menzil kaybı nedeniyle geri
alındı. Pati'nin anlık radyo akımı ölçülmedi; genel veri sayfası
sayıları cihaz ölçümü değildir. Yeni ölçüm olmadan tekrar kısılmıyor.

**CPU 240 → 160 MHz (pilde).** Kayda değer akım kazancı. Ama 20 fps'te
kare bütçesi zaten dardı (160 MHz'de kare 45-49 ms / bütçe 50 ms);
gözler zaten 10 fps'e indiyse bu artık mümkün olabilir.

**Wifi güç tasarrufu (pilde).** Ortalama akımı ciddi düşürür. ⚠️ Ama
`WIFI_PS_NONE` **bilerek** seçilmişti: radyo DTIM aralıklarında uyuyunca
ses tamponu kuruyor ve konuşma kesiliyor. Kullanıcının kırmızı çizgisi
tam da bu.

**Akıllı göz optimizasyonu** — kare hızını düşürmek kaba bir çözüm.
Kalan gerçek kazanç şurada:
- *Sadece değişeni çiz.* Gözler kırpma aralarında sabit; o karelerde iş
  yapılmamalı.
- *Boştayken yavaşla, hareket olunca hızlan.*
- ~~*Konuşma başlarken yükü bırak.*~~ → yapıldı: pilde `konusuyor`
  ifadesinde kare aralığı 200 ms (`PIL_KONUSMA_FPS`). Henüz ölçülmedi.

**Ekranı düşük pilde ayrıca kısmak.** Genel pil parlaklığı %35;
yüzdeye bağlı ek kademe yapılmadı. Kullanıcının
sırasında ekran ışığı sesin altında ama gözlerin üstünde, ve düşük
gerilim–çökme ilişkisi henüz ölçümle görülmedi. Önce `cokme_mv` verisi
birikmeli.

---

## Düşük pil uyarısı

**Neden var:** çocuk Pati'yi her zaman dolu pille kullanmayacak, ve
"şarja tak" diye bir şey söylenmezse pilin bittiğini ancak Pati
sustuğunda anlayacak. Cümlenin ortasında sessizce ölmektense uyarmak
iyi. Kullanıcının kendi isteği.

- Eşik **%20**, histerezisli (%25'in üstüne çıkmadan sönmüyor)
- **Dakikada bir, üç saniye**, tam ekran — turuncu pil sembolü, yüzde,
  altında **ŞARJA TAK**
- USB'de hiç çıkmıyor: şarj olan pil için uyarmak saçma

**Yüzde ham gerilimden hesaplanmıyor.** Gerilim yük altında sarkıyor
(02.09.2026: konuşurken 3784 → 3664 mV, 120 mV). Anlık okumayla yüzde
verilse çocuk her konuştuğunda pil düşüp çıkardı. Onun yerine **son 30
saniyenin tepe değeri** kullanılıyor — sarkma hep aşağı doğru olduğu
için tepe, dinlenmiş gerilime en yakın olan. Cihazda doğrulandı: anlık
3752 mV okunurken yüzde 54'te kaldı, gerilim 3870'e dönünce 55 oldu.

⚠️ **Gerilim → yüzde tablosu ölçülmüş değil** (`pati_guc.cpp`, `EGRI`).
Lityum hücrelerin bilinen boşalma eğrisi. Gerçekten ölçmek için pili
tam doludan tam boşa sabit yükte boşaltmak gerekir; yapılmadı. Yüzde
bir gösterge, yakıt ölçer değil.

🔴 **Uyarı ekranı yalnızca göz görevinden çizilebilir.** Şerit tamponları
ve SPI onun malı; başka görevden çizmek ekranı bozar. `pati_uyari.hpp`
bunu anlatıyor, `gozler_pil_uyarisi()` sadece bayrak bırakıyor.

---

## Nasıl ölçülüyor

🔴 **USB'yi çekince seri kablo da gidiyor.** Pilde tek pencere panel.

```powershell
(Invoke-WebRequest http://pati.local/api/durum -UseBasicParsing).Content
```

`guc` alanı: `kaynak`, `pil_mv`, **`pil_yuzde`**, `pil_dusuk`, `vin_mv`,
`sicaklik_c`, `ses_tavani`, `goz_fps`, `acilis`, **`cokme`**,
**`cokme_mv`** (son arızadan sonraki açılışta ölçülen pil gerilimi;
çökme anının minimumu değildir). `cokme_mv_ani=yeniden_acilis` bu
anlamı açıklar. Alan adı eski panel araçları için korunmuştur.

**`cokme` sayacı cihazda, NVS'te durur** ve açılışı atlatır. Yalnızca
arıza sayılır (brownout, panic, bekçi); düğmeye basmak ve kabloyla
yükleme sayılmaz. Dün gece çökmeler ancak bilgisayardan ağ üzerinden
sayılabiliyordu; çocuğun evinde öyle bir imkân olmayacak, ve yapılacak
işin tamamı "şu değişiklik çökmeyi azalttı mı" karşılaştırması.

**A/B yöntemi:** sayacı not al → USB'yi çek → 5-10 dakika normal konuş
(sallamadan; sallama ayrı bir değişken) → sayaca tekrar bak.

Zemin: **02.09.2026 akşamı, 10 fps ile 9 dakikada 2 çökme.**
(Ondan önceki zemin 20 fps ile 20-60 saniyede birdi.)

⚠️ **Sayaç geliştirme sırasında kirleniyor.** 02.09.2026 gecesi 2'den
17'ye çıktı ve artışın neredeyse tamamı yazılım denemelerindendi:
yığın taşması panic'leri, tam ekran çizim brownout'ları, seri port
açmanın ürettiği sıfırlamalar. Ölçüme başlarken **o anki değeri not
al**, mutlak sayıya bakma.

---

## Pili elle korumak — tuşlar

Çocuk Pati'yi kullanmadığında kapatabiliyor artık; bu, pil ömrünü
uzatmanın yazılımdan bağımsız tek yolu.

- **Yan düğmeye tek tık:** tamamen kapatır (M5PM1 sistem komutu). Pil
  hiç akmaz. Açmak yine tek tık.
- **Mavi tuşa uzun bas:** derin uyku. Ekran ve ses gider ama M5PM1
  ayakta kalır, yani pil **yavaş akmaya devam eder**. Karşılığı aynı
  tuşla geri gelebilmek.

Uzun süre kullanılmayacaksa doğru olan yan düğme.

⚠️ Derin uykunun akımı **ölçülmedi**. "Haftalarca dokunulmazsa biter"
tahmini, ölçüm değil. Merak edilirse yöntem basit: dolu pille uykuya
al, bir gece bekle, panelden `pil_mv`'ye bak.

---

## Karar kuralı

Bir değişiklik çökme sıklığını **belirgin şekilde** azaltmıyorsa **geri
alınır.** Görünümü ya da sesi bedava bozmuyoruz. Bu gece iki değişiklik
tam bu yüzden geri alındı ya da sorgulandı.

## 05.09.2026 — konuşma yolunun kaynak incelemesi

**Durum: yazılım kusurları düzeltildi; pilde resetin bittiği henüz
kanıtlanmadı.** Cihaz açıldıktan sonra panelden sürüm 3.0.9, pil kaynağı ve 0.60
ses sınırı doğrulandı. Konuşma denemesinde reset sayısı 14 → 17 oldu;
yeni açılışlar `brownout` bildirdi. Ham zamanlı kayıt depoya girmeyen
`prototype/olcumler/pil-2026-09-05-once.jsonl` dosyasında.
14 sayısı ilk panel okumasından, sürekli kayıt ise 15'ten başlıyor.

### Kanıtlanan kusur: konuşma tasarrufu atlanıyordu

`gemini_live_client.cpp` ilk ses paketinden **önce**
`StateChanged(Speaking)` üretiyor. `pati_sohbet.cpp` bu olayda
`g_konusuyor=true` yapıyor; ardından ses paketinde gözleri değiştiren
`if (!g_konusuyor)` çalışmıyor. Gözler düşünme ifadesinde kalabiliyor.
Eski 5 fps kararı ise yalnızca ifade adı `konusuyor` ise geçerliydi.
Yüz aracı başka ifade seçtiğinde de tasarruf kayboluyordu.

Düzeltme: yüz geçişi durum olayında yapılır. Güç kararı ayrıca ses
sürücüsünün bildirdiği DMA çalma penceresine bağlandı. Her 512 örneklik
bloktan önce ve yazımdan sonra kilitsiz bir 32 bit damga güncellenir.
Pencere, gerçekten ayrılan DMA kapasitesinin yukarı yuvarlanmış
süresidir (16 × 1024 / 48000 → 342 ms). Tampon dolu değilse bu süre
fazladan tasarruf bırakabilir; gerçek ses bitiş ölçümü değildir.
Sunucu üretimi bitirse veya yüz değişse de kalan ses korunur.

Panelde `guc.goz_fps` artık aynı etkin hedefi gösterir: pilde ses
penceresinde 5, sessizken 10, USB'de 20. Önceden konuşurken de 10
gösteriyordu. Bu hedef FPS'tir; ölçülen kare sayısı değildir.

### Ses yolundaki I2C kaldırıldı

`hoparlor_yaz → etkin_seviye → guc_kaynak → vin_mv` zinciri eskiden
saniyede bir ses görevinden I2C okurdu. Sürücü bir register için üç
kez 100 ms bekleyebilir; VIN iki ayrı register olduğundan hata yolunda
600 ms artı tekrar araları mümkündü. Bunun brownout nedeni olduğu
kanıtlanmadı, ancak ses yolunu bloke edebilen somut bir kusurdu.

VIN ve VBAT açılışta ve mevcut güç gözcüsünde iki saniyede bir alınır.
Ses ve panel aynı atomik örnekleri okur. VIN okuma hatası eski USB
kararını korumaz; gözcü dört saniye örnek üretemezse de karar bilinmiyor
olur ve pil sınırı uygulanır. Kablo geçişi iki saniyeye kadar geç fark edilebilir;
ölçüme başlamadan kaynak alanının `pil` olduğunu doğrula.

### Elenen iddialar ve açık kalanlar

- `cokme_mv`, `cokme_say()` içinde yeni açılışta okunur. Önceki
  belgelerdeki “çökme anındaki gerilim” yorumu yanlıştı. Gerçek
  geçici düşüşü bu alanla veya iki saniyelik panel yoklamasıyla ölçemeyiz.
- Flash ve PSRAM yerel yapılandırmada da 40 MHz; “defaults uygulanmadı”
  bu yerel derleme için geçerli değil. Cihazdaki sürüm ayrıca okunmalı.
- Ses yeniden örnekleyicisinde bu incelemede bir taşma kusuru bulunmadı;
  süre, perde, parça sınırı ve uzun akış testleri geçti. 1.30× değişmedi.
- Konuşma ses paketinin normal işleme yolunda NVS yazısı yok. Kopma,
  uyku veya kullanıcı ayarı ayrı yollardır; bunlar normal ses paketiyle
  karıştırılmamalı.
- Pil sınırı 0.70 geri getirildi. Geçici 0.60 sürümü de resetin bittiğini
  kanıtlamadı. Bu geri dönüş bir güç iyileştirmesi iddiası değildir.

Üretici pilde yüksek sesin reset yapabildiğini açıkça belirtiyor:
[StickS3 ürün belgesi](https://docs.m5stack.com/en/core/StickS3).
Ancak [M5Unified Speaker_Class](https://github.com/m5stack/M5Unified/blob/master/src/utility/Speaker_Class.cpp)
ana ve kanal sesini karesel ölçekler; Pati PCM'i doğrusal çarpar.
Dolayısıyla üreticinin %75 önerisini Pati'nin 0.70'iyle eşitlemek
ve bu sayıya “garantili güvenli eşik” demek doğru değildir.

### Kartta kabul ölçümü

1. Önce çalışan sürüm, kaynak, `cokme`, `acilis` ve pil mV kaydedilir.
2. Düzeltme yüklendikten sonra kaynak `pil` olmalı. Normal sohbet
   sırasında `goz_fps=5`, sessizlikte `10` görülebilmeli.
3. En az 10 dakika aynı konumda, benzer pil aralığında sohbet edilir;
   sonra daha uzun ve daha düşük pil seviyesinde tekrar edilir.
4. Sayaç artarsa yeniden açılıştaki `acilis` kaydı alınır. Brownout
   sürüyorsa besleme sorunu çözülmüş değildir. Panic/bekçi ise yazılım
   hata yolu ayrı incelenir. Tek temiz koşu bütün pil ömrü garantisi olmaz.
5. Sonuç alınmadan bu değişiklik “pilde çökme çözüldü” diye yayımlanmaz.

### İlk kart denemesi başarısız: 3.0.10

USB ile yüklenen 3.0.10'da panel konuşurken 5 fps, sessizken 10 fps
bildirdi; buna rağmen 09:25:41–09:30:27 pil aralığında sayaç 17'den
22'ye çıktı. Beş yeni açılış da `brownout` bildirdi. İlk yeni açılış
09:26:52'de görüldü. Kaydedilen pil örneklerinin en düşüğü 3590 mV;
bu sayı ani gerilim çöküşünün minimumu değildir. Kayıt:
`prototype/olcumler/pil-2026-09-05-sonra.jsonl` (yerel, depoya girmez).
İfade ve I2C kusurları gerçekti, fakat bunları gidermek reseti çözmedi.

### İkinci aday: AW8737A'nın kendi çıkış sınırlaması

[K150 V0.6 şeması](https://m5stack-doc.oss-cn-shenzhen.aliyuncs.com/1207/K150_Stick_S3_PRJ_V0.6_20251111_2025_11_17_16_10_24.pdf)
sayfa 3'te U19 **AW8737A** ve beslemesi **VBUS_L0**. Önceki
“hoparlör amfisi L3B'den beslenir” ifadesi yanlıştı; L3B ses kodeğini
besler. Amfinin SHDN girişi M5PM1 PYG3'e bağlıdır.

[AW8737A veri sayfası](https://doc.awinic.com/doc/20230609wm/ba30d80d-55b2-46f8-8f8a-505cd74a8826.pdf)
sayfa 8, 19 ve 20: SHDN'yi yalnızca yükseltmek Mode1'i seçer;
8 ohm yükte nominal NCN sınırı 1,2 W'tır. Mode4'te bu değer 0,6 W'tır.
Küçük sinyal kazancı kipler arasında değişmez. Bunlar veri sayfası
değerleridir; kartta watt veya darbe gerilimi ölçülmedi. PCM çarpanı
0.70 ile amfinin 0,6 W sınırlaması farklı şeylerdir. Eski yazılım
yalnızca SHDN'yi yükseltiyordu; tepe seslerde bu daha yüksek güç
talebine yol açabilir. Resetin ana nedeni olduğu henüz kanıtlanmadı.

3.0.11 adayı, SHDN'yi 20 ms düşük tutup Mode4'ü M5PM1'in darbe
üreteciyle seçer. I2C'den mikro saniyelik darbeler üretmeye çalışmaz.
[M5PM1 sürücüsünün](https://github.com/m5stack/M5PM1/blob/main/src/M5PM1.cpp)
`setAw8737aMode` yoluyla aynı NUM=3, GPIO=3, REFRESH komutunu kullanır.
Register geri okunamaz veya uyuşmazsa hata döner; yüksek güç kipine
sessiz bir geri dönüş yoktur. Panelde `amfi_kipi=4` komut ayarının
geri okunduğunu gösterir, analog gücün ölçüldüğünü değil.

Ayar USB'de de aynıdır; kaynak geçişinde ses döngüsüne I2C eklenmez.
Yeniden örnekleme 1.30× ve pil PCM sınırı 0.70 korunur; yüksek ses
tepelerinde sıkıştırma duyulabilir.

Kartta 3.0.11 ve `amfi_kipi=4` geri okuması doğrulandı. İlk kayıtta
09:44:22–09:49:39 pil aralığında sayaç 22'de kaldı; sonraki kontrolde
24 ve son açılış `brownout` görüldü. Aradaki iki resetin zamanı kayıt
dışında kaldığı için sıklık karşılaştırması yapılamaz. Reset sorunu
çözülmüş sayılmaz.

Kullanıcı daha sonra sessizlik bildirdi. USB'deki seri kayıtta mikrofon
ve Gemini ses çözümü çalışıyordu; kullanıcı önce USB'de, ardından pilde
ses geldiğini doğruladı. Bu arada firmware değişmedi. Sessizliğin
nedenini amfiye bağlayan kanıt yok. 14:34 kontrolünde kaynak pil,
sayaç 24; yeni koşu `prototype/olcumler/pil-2026-09-05-sessizlik.jsonl`
dosyasına kaydediliyor. Kısa süreli ses dönüşü reset çözümü değildir.

## 09–10.09.2026 — USB bağlıyken konuşmada brownout

Kullanıcı pilde resetlerin çok azaldığını, bilgisayar USB'sinde ise
sıklaştığını bildirdi. Motor/servo bağlı olmadığını doğruladı.
Seri kayıtta çalışan sürüm 3.5.0 ve arızalı açılış sayısı 48;
reset nedeni brownout. Kullanıcının yan tuşla yaptığı ayrı kapanma
arıza sayılmadı. Sonraki ağ kayıtlarında sayaç 49 → 50 oldu.
Kaynak USB; açılışta VIN 4942 mV, ses tavanı 1.00. Bu VIN değeri
reset anındaki minimum değildir.

USB'de pilin 0.70 sınırı kalkıyor, ekran %100 ve 20 fps oluyor.
Panelden 0.70 isteği kabul edildi ve hemen geri okundu; sonra reset
oldu ve ayar 1.00'a döndü. Ses seçimi yalnız RAM'de tutuluyor.
Bu kısa deneme, kesintisiz ve doğrulanmış uzun bir 0.70 A/B koşusu
değildir; yalnız ses kısmanın yeterli olduğu kanıtlanmadı.

Ham kayıtlar depoya girmeyen prototype/olcumler altında:
usb-2026-09-09-reset.log ve usb-ses070-2026-09-10.jsonl.
Google TLS zaman aşımı da görüldü; brownout ile karıştırılmamalı.
Sıradaki ayrım aynı kabloyla bilgisayar portu / şarj adaptörü;
sonra gerekirse USB'deki ekran yükü ayrı sınanacak. Henüz düzeltildi
diye bir sonuç yok.

3.5.1 test adayı: USB'de de ekran %35, gözler 10/5 fps ve ses tavanı
0.70. Paneldeki ses_tavani doğrudan ses sürücüsünün kullandığı işlevden
okunur; USB var diye sınırsız güç varsayılmaz. Kaynak USB olarak kalır;
şarj göstergesi ve OTA korumaları değiştirilmedi. USB portu/adaptör
karşılaştırmasını kullanıcı istemedi; bu aday yükleri birlikte azaltır,
etkili olsa bile tek yükün kök neden olduğunu kanıtlamaz. Kart testi
sonucu aşağıda. Yeniden örnekleme ve Puck 1.30× değişmedi.

Sonuç: 3.5.1 kartta USB, 0.70 tavan ve konuşurken 5 fps olarak
doğrulandı. 00:04:42 başlangıcında sayaç 51; 00:06:38'de 52 ve
brownout görüldü. Kayıt: usb-tasarruf-2026-09-10.jsonl. Profil reseti
durdurmadı, belirgin kazanç kanıtlanmadı; kaynak değişikliği geri
alındı, yayımlanmadı. Kablo/port/şarj devresi karşılaştırması yapılmadan
bu parçalar arasında kök neden ayrımı yapılamıyor.

### Amfi kapalı ayrıştırma denemesi

10.09.2026 00:14:14–00:18:13, aynı USB bağlantısında yalnız
hoparlör amfisi açılışta kapalı tutuldu. Mikrofon, ağ, yeniden örnekleme,
I2S ve ekran çalışmaya devam etti; panel amfi=0, göz=20 fps,
ses tavanı=1.00 gösterdi. Kullanıcı 20–30 saniye arayla soru sormayı
kabul etti. 117 ağ örneğinde sayaç 54 → 54; 12 örnekte ifade
`konusuyor` idi. Örnekler cevap sayısı değildir; kısa cevaplar iki
saniyelik yoklamalar arasına düşebilir. Kayıt:
`prototype/olcumler/usb-amfi-kapali-2026-09-10.jsonl`.

Bu kısa koşuda reset görülmemesi, amfi/hoparlör güç yükü ihtimalini
destekler; arıza aralıklı olduğundan kök neden kanıtı değildir.
Amfi arızası, besleme zayıflığı ve kısa akım tepeleri ayrılmadı.
Geçici sessiz sürüm yayımlanmadı; resmi 3.5.0 imajı USB'den geri
yüklendi ve panelden doğrulandı (amfi=4, ses=1.00, Puck 1.30×).
İlk başarılı geri okumada sayaç 55 ve brownout; 00:20:08'de sayaç
56 idi. Kullanıcı sesin geldiğini ve konuşurken üç çökme gördüğünü
bildirdi. Bu bildirim, kayıtta sayılan iki artıştan ayrı tutulmalı;
geri yükleme ile ilk erişim arasındaki olayların zamanı bilinmiyor.
Normal sürüme dönüş kaydı:
`prototype/olcumler/usb-amfi-acik-donus-2026-09-10.jsonl`.
00:21:52'de konuşma örneğinden sonra 00:21:57'de sayaç 57;
00:22:18'de ayrı doğrulamada 58 ve brownout görüldü. Böylece normal
sürüme dönüşten sonraki toplam artış dört oldu (54 → 58).
Son doğrulama: `usb-amfi-geri-yukleme-dogrulama-2026-09-10.json`.
Dönüş izleme dosyasında sürüm alanı yanlış JSON yolundan okunduğu
için null; sürüm 3.5.0 ayrı doğrulamada `guncelleme.su_anki` alanından
okundu. Ham kayıttaki null değerler sonradan doldurulmadı.

AW8737A veri sayfası V1.2 s.8 ve s.16 yeniden kontrol edildi:
Mode4, 8 ohm + 33 µH test yükünde nominal 0.6 W ile en düşük
NCN güç seçeneğidir; dört kipte de küçük sinyal kazancı aynıdır.
NCN kazancının 13.5 dB azalması için belirtilen süre 40 ms'dir.
Bu yüzden 0.6 W seçimi anlık tepe akımını kesin sınırlıyor varsayımı
yanlıştır. Ancak bu kartta böyle bir tepe henüz ölçülmedi. Belgelenen
dört kip arasında daha düşük güç ya da ayarlanabilir saldırı süresi
yoktur. PMIC kip geri okuması fiziksel SHDN darbe ölçümü değildir.
Kaynak: https://doc.awinic.com/doc/20230609wm/ba30d80d-55b2-46f8-8f8a-505cd74a8826.pdf

### Bağlantı toparlamasında doğrulanan ayrı kusur

`usb-2026-09-09-reset.log` içinde 128223 ve 138403 ms'de yeniden
bağlanma girişimleri var. Her ikisi 22 ms sonra başarılı yazılıyor;
arada TLS zaman aşımı geliyor ve sonraki girişim yine deneme 1.
İstemcinin `start()` işlevi WebSocket görevini başlatıp hemen dönüyor;
sunucunun hazır oluşu daha sonraki `setupComplete` ile bildiriliyor.
Toparlama kodu erken başarıda sayacı sıfırladığı için asenkron bağlantı
hatalarında artan bekleme çalışmıyordu. Başarı artık güncel istemcinin
Listening durumunda doğrulanıyor; start sırasında gelen hata bayrağı
da dönüşte silinmiyor. Uzun kesintideki sınırsız bit kaydırma düzeltildi.

`firmware/test/yeniden_baglan_test.py` gerçek toparlama gövdesini sahte
istemciyle derleyip asenkron başarısızlık, 2/4/8/16/30 saniyelik bekleme,
eski hazır olayı, anında hata ve sayaç sınırlarını doğruluyor.
Firmware derlemesi ve dört mevcut konak testi geçti. Bu yazılım
kusuru, brownout'un kök nedeni olarak kanıtlanmadı. Derlenen düzeltme
ilk aşamada cihaza yüklenmedi; çalışan kart 3.5.0 olarak bırakıldı.

Kullanıcının yükleme isteğiyle 10.09.2026'da 3.5.1 USB'den yüklendi.
İlk yükleme kontrolünde amfi=0 görüldü: sessiz testten geri kopyalanan
kaynağın eski zaman damgası nedeniyle artımlı derleme eski nesneyi
kullanmıştı. `idf.py clean build` sonrası yeniden yüklendi; flash özeti
doğrulandı. 00:35:02 panel doğrulaması: sürüm 3.5.1, amfi=4,
ses=1.00, Puck 1.30×, göz=20 fps, sayaç=62, açılış=diger.
Kayıt: `prototype/olcumler/usb-3.5.1-baglanti-duzeltme-yukleme.json`.
Bu açılış kontrolü uzun süreli reset testinin yerine geçmez.

00:48:13 kontrolünde 3.5.1, USB, amfi=4, ses=1.00, göz=20 fps;
sayaç 67, son açılış brownout. 00:35:02'deki 62 başlangıcından
yaklaşık 13 dakika 12 saniyede beş arızalı açılış birikmiş.
Kullanıcı belirgin azalma bildirdi; bu aralıkta etkin konuşma süresi
ve bağlantı yenileme sayısı ölçülmediği için önceki koşuyla kontrollü
sıklık karşılaştırması yapılamaz. Bağlantı kusuru düzeltildi, fakat
brownout sürüyor; ortak kök neden veya tetikleyici bağı kanıtlanmadı.

## 3.5.2 — şarjda kullanıcı tarafından seçilen tasarruf

Şarjda gözler sessizken 20, gerçek ses/DMA penceresi boyunca 10 FPS;
pildeki 10/5 FPS korunuyor. İki kaynakta da parlama tek kat, cam
parlaması kapalı, ekran %35 ve etkin ses tavanı 0.70. Daha düşük ses
seçimi korunur. Panel tavanı doğrudan ses sürücüsünden alır. Puck 1.30×,
Wi-Fi gücü ve uyku ayarı değişmedi. Flash zaten 40 MHz; yeni kazanç
olarak sayılmaz. Kaynak ayrımı korunur; şarj göstergesi ve OTA pil
korumaları aynı kalır. Kullanıcı güncellemeyi panelden yükleyecek.
Bu profilin resetlere etkisi henüz kartta ölçülmedi.

## 11.09.2026 — 3,7 dakikalık kesintisiz kayıt (USB, konuşurken)

3.5.3 yüklü, USB takılı, kullanıcı konuşurken panelden 10 saniyede bir
`api/durum` çekildi. Ham kayıt: `usb-izleme.jsonl` (23 başarılı örnek,
22:06:44 → 22:10:28; ardından cihaz kapatıldığı için ulaşılamadı).

| Saat | pil_mv | vin_mv | çökme | cokme_mv | °C | RSSI |
|---|---|---|---|---|---|---|
| 22:06:44 | 3740 | 5002 | 19 | 3736 | 53,5 | **−70** |
| 22:07:04 | 3714 | 4932 | 19 | 3736 | 52,5 | **−69** |
| 22:07:14 | 3744 | 4992 | 19 | 3736 | 53,5 | **−71** |
| 22:07:24 | 3744 | 4988 | 20 | 3742 | 53,5 | **−49** |
| 22:07:44 | 3746 | 4984 | 21 | 3746 | 54,5 | −57 |
| 22:07:55 | 3752 | 4992 | 22 | 3750 | 54,5 | −54 |
| 22:08:07 | 3750 | 4996 | 23 | 3750 | 53,5 | −60 |
| 22:08:27 | 3752 | 4986 | 24 | 3750 | 54,5 | −53 |
| 22:08:37 | 3754 | 4990 | **25** | 3754 | 54,5 | −51 |
| 22:09:27 | 3758 | 4992 | 25 | 3754 | 54,5 | −52 |
| 22:10:28 | 3770 | 4992 | **25** | 3754 | 54,5 | −52 |

### ⚠️ Geri çekilen okuma: "gerilim düz, hiç şarj olmuyor"

İlk dört örneğe (3740 → 3714 mV) bakılıp *"pil bir dakikada hiç
yükselmedi, USB çalışırken hiç şarj etmiyor"* denmişti. **Yanlıştı.**
Tam pencerede gerilim 3740 → 3770 mV yükseliyor: yaklaşık 8 mV/dakika.
Yani çalışırken şarj **oluyor**, sadece yük karşısında çok yavaş. İlk
dakikadaki düşüş bir eğilim değil, anlık örneğin yükle salınmasıydı.

Ders eskisiyle aynı: **aralıklı bir sistemde bir dakikalık pencere bir
eğilim göstermez.**

### ⚠️ `pil_mv` ile `pil_yuzde` aynı büyüklük değil

Panelin iki alanı farklı şeyler veriyor ve bu koşuda karıştırıldı:

| Alan | Ne | Kaynak |
|---|---|---|
| `guc.pil_mv` | **anlık** son örnek, ham | `g_pil_mv` (`pati_guc.cpp` · `pil_mv()`) |
| `guc.pil_yuzde` | son 30 saniyenin **TEPE** değeri, eğriden çevrilmiş | `g_pencere[15]` · `pil_yuzde()` |

Kayıttaki iki tuhaflığı tam olarak bu açıklıyor:

- **22:08:07'de `pil_yuzde` = −1.** Bu bir hata değil, belgeli nöbetçi
  değer: `if (tepe <= 0) return -1` — pencere boş. Pencere kaynak
  değişince sıfırlanıyor ve o örnekte çökme sayacı 22 → 23 oldu, yani
  cihaz yeni açılmıştı.
- **22:09:27'de `pil_mv` 3758 iken `pil_yuzde` %46.** Eğriden 3758 mV
  doğrudan %32 verir; %46 için tepenin ~3825 mV olması gerekir. Yani
  pencerede, anlık örneklerin 67 mV üstünde bir şarj devresi okuması
  kalmıştı.

🔴 **Sonuç: tablodaki `pil_mv` sütunu tepe değil, 10 saniyede bir
alınmış anlık örnektir.** Konuşma sırasındaki gerçek milisaniyelik
çöküntüler bu örnekleme aralığıyla **hiç görülemez**. Brownout'un
gerçekleştiği gerilim bu sütunda yazmıyor ve `cokme_mv` de onu
vermiyor — o da aynı anlık okumadan geliyor.

Bu belge (§"Elenen iddialar", 05.09) ve `TESHIS.md` bunu zaten doğru
yazıyordu. **Geride kalan tek yanlış yer kaynak koddu:** `pati_guc.cpp`
içinde `cokme_mv` yazılırken duran yorum hâlâ *"düşük pil hipotezinin
sınandığı yer burası"* diyordu. 11.09'da düzeltildi — `app_main.cpp`
ile `pati_ses.hpp` arasında çıkan çelişkinin aynısı: belge geri
çekiliyor, kaynaktaki kopya kalıyor.

### 🔴 Asıl bulgu: çökmeler durdu ve sinyalle örtüşüyor

- 22:06:44 → 22:08:37 arası **113 saniyede 6 çökme** (19 → 25), yani
  ortalama 19 saniyede bir.
- 22:08:37 → 22:10:28 arası **111 saniyede 0 çökme.** Sayaç 25'te kaldı.
- Aynı anda RSSI **−70/−71'den −49/−52'ye** çıktı (22:07:24'te sıçradı).
  `cubuk()`'a göre bu 2 çubuktan 4 çubuğa geçiş.

Pil gerilimi iki yarı arasında neredeyse aynı (3754 → 3770 mV, 16 mV).
Sıcaklık aynı (53,5–54,5 °C ikisinde de). vin aynı (~4990 mV, tek
istisna 4932'lik bir örnek). **Değişen tek ölçülen büyüklük sinyal.**

Bu, bu belgenin kendi tablosuyla tutarlı: satır 83'te wifi vericisi
20 → 15 dBm denemesi *menzil çöktüğü için* geri alınmış ("modemin
dibinde bile zor çekiyor") ve aynı satırda telsizin gönderirken
250–350 mA çektiği yazılı. Yani Pati zaten menzilinin sınırında
çalışıyor; zayıf sinyalde verici tam güçte kalıp yeniden gönderim
yapıyor ve bu darbeler yarı boş bir hücrenin üstüne biniyor.
`WIFI_PS_NONE` (radyo hiç uyumuyor) bu tabloyu ağırlaştırıyor —
`pati_ag.cpp` yorumu bedelini zaten "~30 mA fazla ortalama" diye
yazmış, ama tepe akımı ayrı bir şey.

### Bu KANIT DEĞİL — neyin karıştığı

1. **Kullanıcının konuşmaya devam edip etmediği bilinmiyor.** Sessiz
   geçen iki dakika, çökmelerin durmasını tek başına açıklar.
2. RSSI 22:07:24'te düzeldi ama çökmeler **73 saniye daha sürdü.**
   Sebep-sonuç olsaydı daha keskin bir kesme beklenirdi (ya da
   yeniden bağlanma/kota sarmalının ataleti sayılmalı).
3. n = 1. Tek geçiş, tek pencere.
4. Hücre %30'da; bu koşulda alınan hiçbir ölçüm temiz değil.

### Sıradaki ayrım — pil dolduktan sonra

Şarj bitince iki soru **ayrı ayrı** ölçülecek, ikisi de kod
değişikliği gerektirmiyor:

1. **Dolu pille çökme sıklığı.** Hücre ~4,1 V iken aynı konuşma.
   Çökme kalmazsa gerilim payı; sürerse gerilim ana sebep değil.
2. **Sinyal A/B.** Aynı pil seviyesinde, önce modemin yanında sonra
   uzağında birer koşu. Ölçülen: dakikada çökme ve RSSI.

⚠️ İzleme betiği bundan sonra `ag.tx_ceyrek_dbm` ve `ag.tasarruf`
alanlarını da kaydetmeli; paneldeki JSON'da ikisi de zaten var
(`pati_panel.cpp`) ve bu koşuda kaydedilmedikleri için verici
gücünün gerçekten tavanda olup olmadığı söylenemiyor.

⚠️ **Önce ölçüm, sonra kod.** Wifi tarafında akla gelen iki kol
(verici gücünü kısmak, `WIFI_PS_MIN_MODEM`'e dönmek) ikisi de daha
önce bilinçli olarak reddedilmişti: birincisi menzili öldürdü,
ikincisi sesin ortasında boşluk yapıyor. Ölçüm olmadan ikisi de
açılmaz.

## 3.5.4 — pil/şarj profil ayrımı kaldırıldı

Kullanıcının kararı (11.09.2026): *"pil modu şarj modu ayrımını
kaldıralım, mod olmasın, her şey pildeki gibi çalışsın, ister şarjda
olsun ister pilde."*

### Ayrımın dayandığı varsayım ölçümle çöktü

Gerekçe *"USB'de akım bol, sınırları gevşetebiliriz"* idi. 11.09.2026
akşamı aynı kartta sırayla ölçüldü — **üçünde de konuşurken brownout**:

| Koşul | Pil | Sonuç |
|---|---|---|
| USB (bilgisayar portu) | **4048 mV** (neredeyse dolu) | çöktü, `cokme_mv` 4048 |
| Pil, gövde çıkarık | 3950 mV | çöktü, 23:09:28'de canlı yakalandı |
| Tam silme + temiz yükleme sonrası | 3950 mV | yine çöktü |

🔴 **Dolu pille çökme, "hücre düşük olduğu için" açıklamasını bitiriyor.**
USB fazladan pay vermiyor; yalnızca yazılım sınırlarını kaldırıyordu.

### Ne değişti

Tek gerçek fark göz kare hızıydı — ses tavanı 3.5.2'de zaten iki
kaynakta da 0.70'e eşitlenmişti.

| | Eskiden şarjda | Eskiden pilde | **3.5.4** |
|---|---|---|---|
| Sessizken | 20 FPS | 10 FPS | **10 FPS** |
| Konuşurken | 10 FPS | 5 FPS | **5 FPS** |

`gozler_pil_kipi(bool)` **kaldırıldı** — bir profil seçicisi bırakmak,
ileride birinin "şarjda hızlandıralım" diye geri açmasına davetiye
olurdu. Kare hızının artık güç kaynağı diye bir girdisi yok.

Konak testi bunu koruyor: 200 adımlık tarama, ses penceresi açık ya da
kapalı, saat nerede olursa olsun çıkan değerin **yalnızca 10 ya da 5**
olabildiğini doğruluyor. Eskiden USB'de 20 çıkıyordu; o sayının bir daha
görünmemesi gerekiyor.

### Yan bulgu: log kodun yaptığını değil eski hâlini anlatıyordu

`app_main.cpp`'deki güç kaynağı logu ses tavanını
`pilde ? min(seviye, TAVAN) : seviye` diye **kendisi hesaplıyordu** ve
3.5.2'den beri yanlıştı: tavan o sürümde iki kaynakta da geçerli oldu
ama log USB'de hâlâ sınırsız seviye basıyordu. Artık fiilen uygulanan
değeri kaynağından okuyor (`ses_etkin_seviye()`).

⚠️ Teşhiste en pahalı yanlış türü bu: log doğru görünüyor ama ölçtüğü
şey kodun yaptığı şey değil.

### ⚠️ Bu değişikliğin bu akşamki çökmeleri durdurması BEKLENMİYOR

Kullanıcı ölçüm sırasında **pildeydi**, yani 10/5 profili zaten
çalışıyordu. Bu sürüm yalnızca **şarjdaki** yükü pildekine indiriyor.
Kazanç varsa USB'de görünür ve henüz ölçülmedi.

Değişikliğin gerekçesi "çökmeyi çözer" değil: **kaynağa göre fazladan
yük vermenin dayanağı kalmadı.**

### 3.5.4'ün ikinci yarısı — konuşma başı rampası, parlaklık, CPU

Kullanıcının isteği: *"kaliteyi bozmamaya çalış, bir de ekran
parlaklığından da tasarruf edebiliriz, CPU'dan tasarrufun yanında."*
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

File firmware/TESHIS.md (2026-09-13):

# Teşhis — kesilme, donma, çökme

Pati "cevap vermiyor", "ses kesiliyor", "kendiliğinden yeniden başlıyor"
dendiğinde bakılacak yer burası.

Bu belge 01.09.2026'da yaşanan uzun bir teşhis oturumundan çıktı. O gün
**dört ayrı belirti tek bir kök nedene** bağlandı ve yolda birkaç yanlış
teşhis yapıldı. Yanlış teşhisler de yazılı: aynı tuzağa tekrar düşülmesin.

---
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

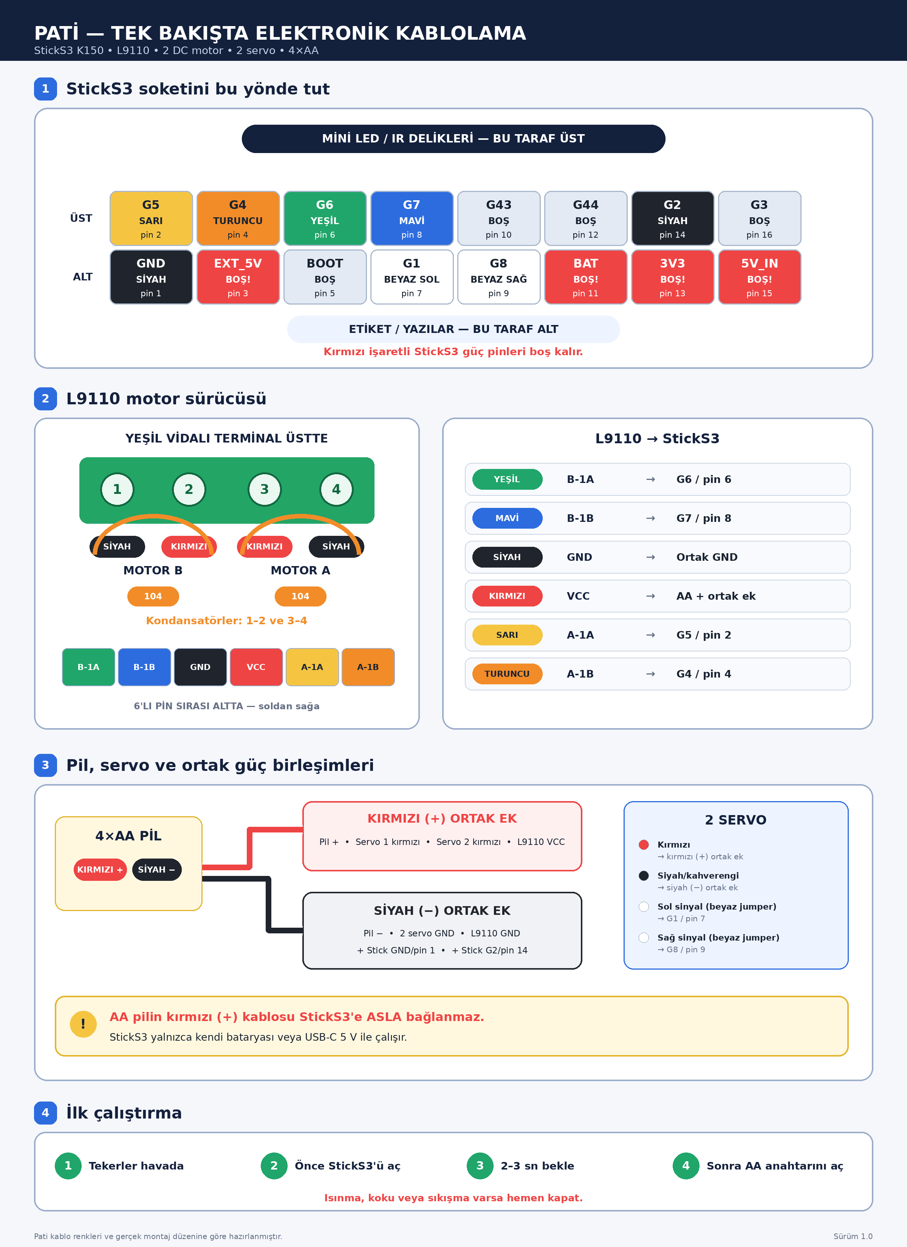
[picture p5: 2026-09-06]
firmware/Pati_Tek_Bakis_Kablolama_Diyagrami.png

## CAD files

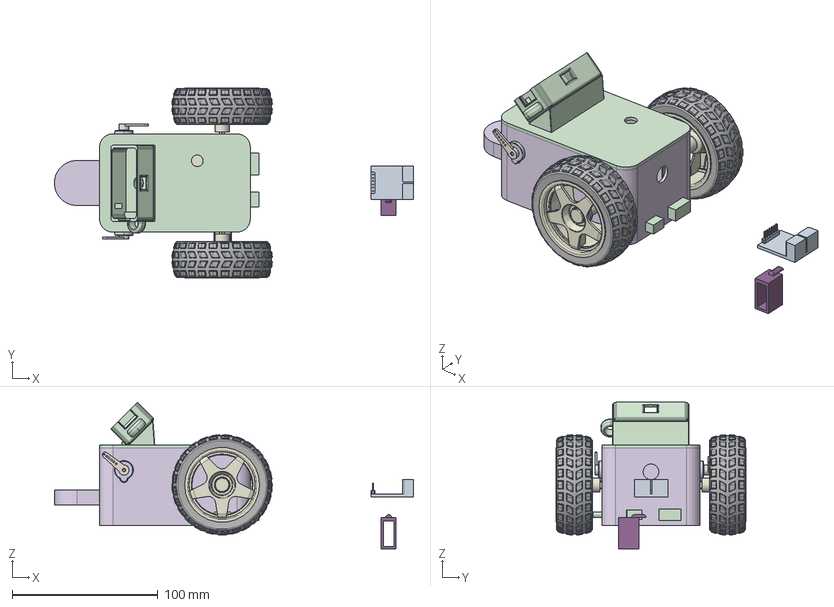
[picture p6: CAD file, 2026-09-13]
enclosure/cad/pati-assembly.step
246.3 x 130.1 x 100.6 mm
powerbank
dcmotor
govde
servo
servo2
По умолчанию
ust
casee
kablo
driver

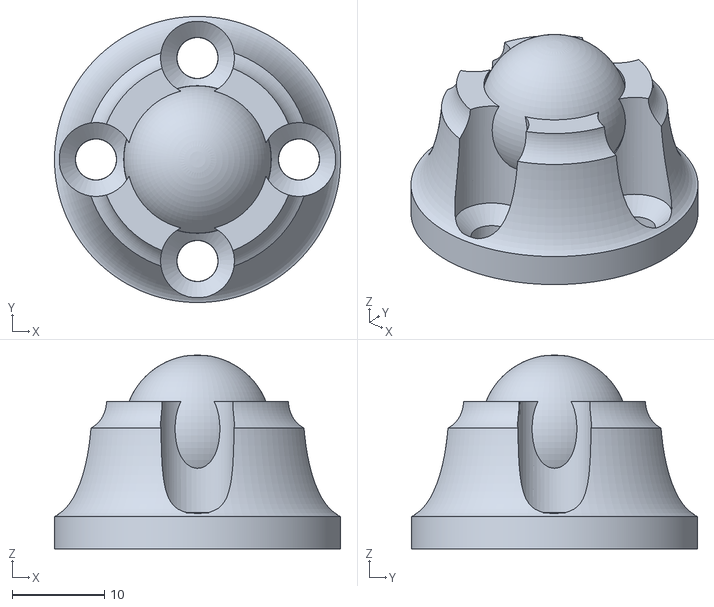
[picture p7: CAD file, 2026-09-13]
enclosure/print/ball-caster.stl
31.0 x 31.0 x 21.0

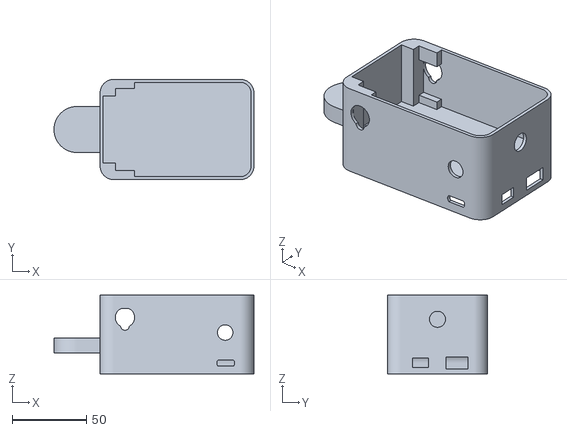
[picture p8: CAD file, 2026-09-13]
enclosure/print/body.stl
134.5 x 67.5 x 52.9

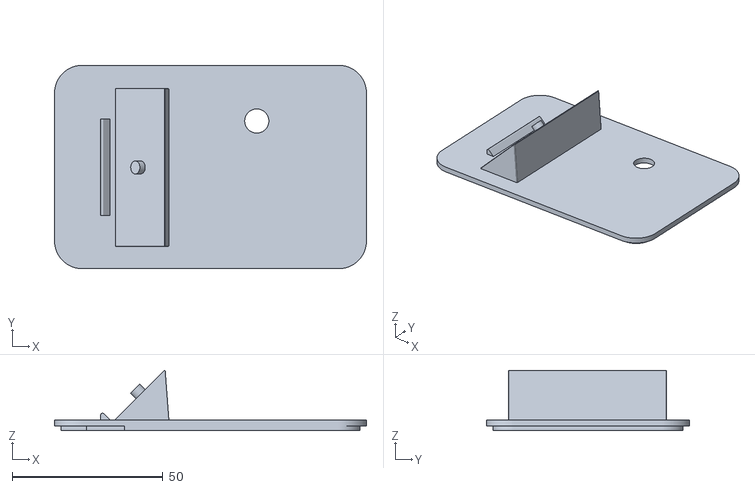
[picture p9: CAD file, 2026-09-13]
enclosure/print/body-top.stl
103.5 x 67.5 x 20.1

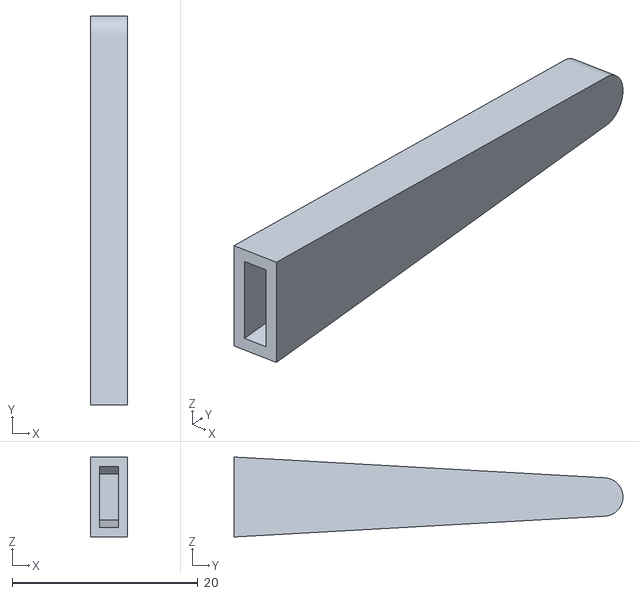
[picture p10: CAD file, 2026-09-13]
enclosure/print/arm.stl
4.00 x 41.8 x 8.60

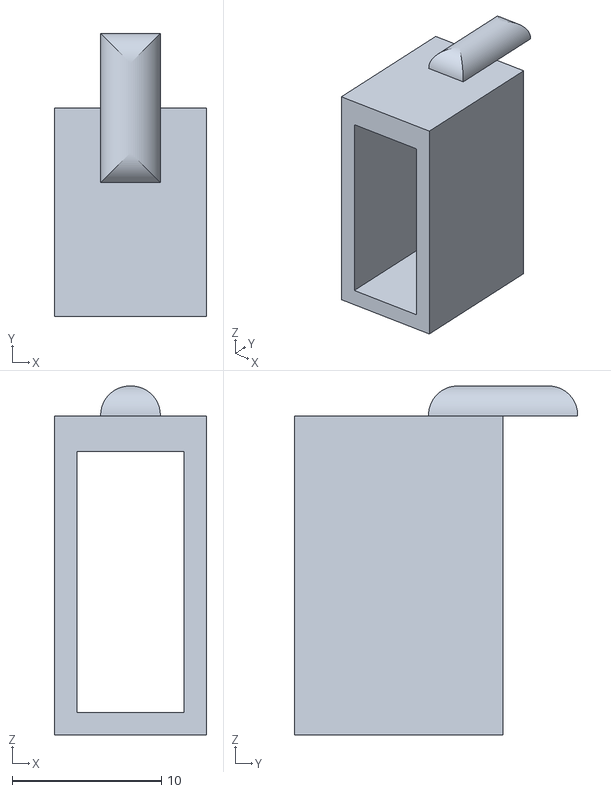
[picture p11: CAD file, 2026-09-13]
enclosure/print/sticks3-cable-plug.stl
10.2 x 19.0 x 23.4

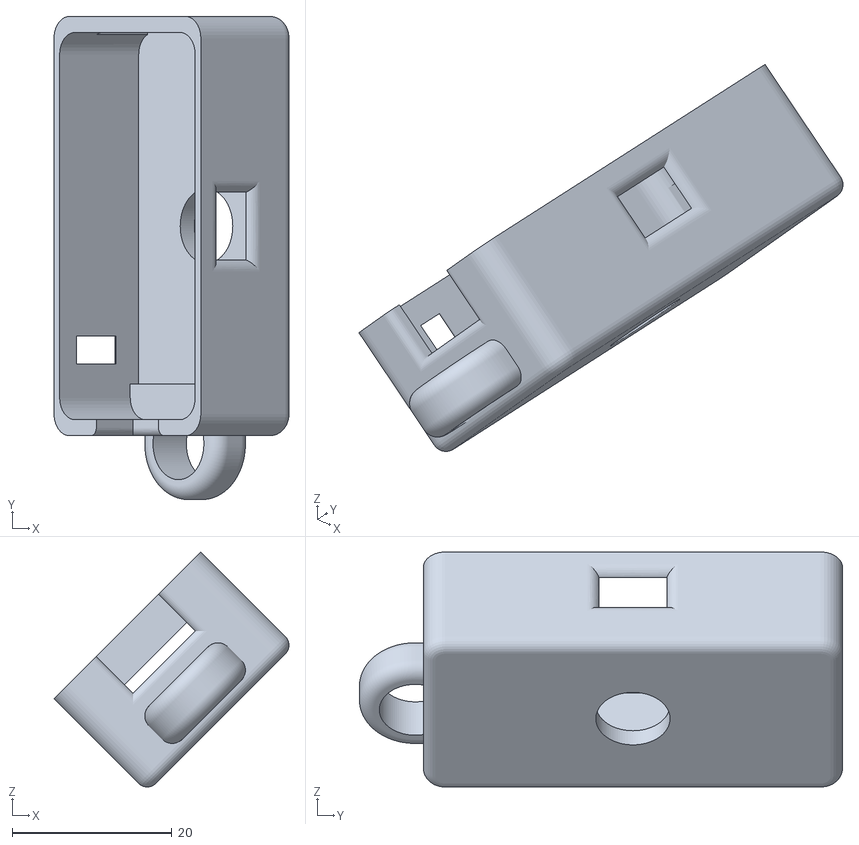
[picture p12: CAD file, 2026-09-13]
enclosure/print/sticks3-case.stl
29.4 x 60.5 x 29.4

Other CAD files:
enclosure/cad/pati-assembly.x_t

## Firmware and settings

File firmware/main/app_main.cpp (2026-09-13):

// Pati — StickS3 açılışı, güç gözcüsü, panel ve sohbet yaşam döngüsü.
// Donanım yoklaması OTA onayından önce kalmalı; yanlış karta gelen
// güncellemenin geri dönebilmesi bu sıraya bağlı.

#include <algorithm>
#include <array>
#include <cinttypes>
#include <cstdlib>
#include <memory>

#include <esp_chip_info.h>
#include <esp_heap_caps.h>
#include <esp_log.h>
#include <esp_ota_ops.h>
#include <esp_psram.h>
#include <esp_system.h>
#include <esp_timer.h>
#include <freertos/FreeRTOS.h>
#include <freertos/task.h>
#include <nvs_flash.h>

#include <conversation/gemini_live_client.hpp>

#include "pati_beden.hpp"
#include "pati_ekran.hpp"
#include "pati_gozler.hpp"
#include "pati_guc.hpp"
#include "pati_hafiza.hpp"
#include "pati_olcum.hpp"
#include "pati_pinler.h"
#include "pati_ses.hpp"
#include "pati_sohbet.hpp"
#include "pati_tus.hpp"
#include "pati_ag.hpp"
#include "pati_anahtar.hpp"
#include "pati_ayar.hpp"
#include "pati_guncelleme.hpp"
#include "pati_kullanim.hpp"
#include "pati_panel.hpp"

namespace {

constexpr const char* ETIKET = "pati";

// Kac turda bir tam rapor basilsin.
//
// Kosu bitmesini beklemiyoruz: 20 dakikalik bir kosuda gecikmenin
// zamanla artip artmadigini gormek istiyoruz (PC'de baglam buyudukce
// +283 ms olculmustu).
constexpr std::uint32_t RAPOR_ARALIGI = 5;

// Olumcul hata: sebebi yukarida yazili, program burada duruyor.
//
// NEDEN CIKMIYORUZ: app_main donerse ESP32 yeniden baslar ve seri
// porttaki hata mesaji akip gider. Burada bekleyip hatanin okunmasini
// sagliyoruz.
void bekle_ve_dur()
{
    ESP_LOGE(ETIKET, "");
    ESP_LOGE(ETIKET, "Program durdu. Yukaridaki sebebi duzeltip");
    ESP_LOGE(ETIKET, "karti yeniden baslat (RESET dugmesi).");
    while (true) {
        vTaskDelay(pdMS_TO_TICKS(10000));
    }
}

// -------------------------------------------------------------------------
// GUC GOZCUSU — kaynagi izler, kipi uygular, dusuk pili haber verir
// -------------------------------------------------------------------------
//
// 🔴 NEDEN AYRI GOREV. Bu is eskiden ana dongudeydi ve ana dongu ancak
// SU UCU BITINCE basliyor: wifi baglanmasi, anahtarin girilmis olmasi,
// ilk Gemini oturumunun acilmasi. Yani acilistan itibaren saniyelerce
// guc kipi HIC uygulanmiyordu.
//
// 02.09.2026'da olculdu — brownout'tan yeni kalkmis bir cihazda:
//
//     19:16:04  cokme=1  goz_fps=20   <- yeniden basladi, gozler tam hizda
//     19:16:10  cokme=1  goz_fps=10   <- pil kipi ANCAK simdi girdi
//
// Alti saniye boyunca Pati en kirilgan aninda — pil zaten dusuk, telsiz
// baglaniyor (en yuksek akim), TLS el sikismasi CPU yiyor — ustune
// gozleri de tam hizda cizti. Wifi yavas baglansa bu pencere yirmi
// saniye olurdu.
//
// Ayri gorev bunu ORTADAN KALDIRIYOR: gozler acilir acilmaz basliyor ve
// hicbir seyi beklemiyor.
//
// Yigin 3072: I2C okumasi, birkac karsilastirma ve ESP_LOG. Olculen
// tepe kullanim buna rahat siginiyor.

// Yoklama araligi. 2 saniye, cunku pil yuzdesi 30 saniyelik pencerenin
// TEPESINDEN hesaplaniyor (pati_guc.cpp) ve 15 ornek istiyor.
constexpr int GOZCU_ARALIK_MS = 2000;

// Dusuk pil uyarisi ne siklikta gorunsun.
//
// Kullanicinin istegi: "pil %20'nin altina dusunce dakikada bir sarja
// tak diye bir sey gosterebiliriz". Dakikada bir, uc saniye — sohbeti
// bolmeyecek kadar seyrek, unutturmayacak kadar sik.
constexpr std::int64_t UYARI_ARALIK_US = 60LL * 1000000LL;

// Guc kipini uygular. Kaynak degisince ve acilista bir kez cagriliyor.
// 🔴 ARTIK PROFIL SECMIYOR — 11.09.2026, kullanicinin karari.
//
// Adi "guc kipi uygula" ama iki kip kalmadi: TEK kip var ve kaynaktan
// bagimsiz. Islev yine de duruyor, cunku iki isi var: acilista ve kaynak
// degisince ayarlari yeniden basmak, ve kaynak degisimini LOGA yazmak.
// Log teshis icin degerli — hangi an neye gecildigi gorunuyor.
//
// Neden ayrim kalkti: "USB'de akim bol, sinirlari gevsetebiliriz"
// varsayimi olcumle coktu. 11.09.2026'da ayni kartta, ayni aksam:
// USB'de dolu pille (4048 mV) brownout, pilde (3950 mV) brownout, tam
// silme ve temiz yuklemeden sonra yine brownout — hepsi konusurken.
// Kaynaga gore fazladan yuk vermenin bir karsiligi kalmadi.
void guc_kipi_uygula(pati::GucKaynagi kaynak)
{
    // ---- ARKA IŞIK: her kaynakta %35 -----------------------------------
    //
    // Sürekli ekran yükünü azaltarak konuşma anına güç payı bırakmak
    // amaçlanıyor. Resetlerin kök nedeni ve bu ayarın etkisi ölçülecek.
    //
    // ⚠️ OLCULMUS DEGERLER DEGIL. 0.45 tek basina denendi ve cokmeyi
    // durdurmadi (bkz. PIL.md); yine de taban akimi dusurdugu icin
    // duruyordu. 02.09.2026'da kullanicinin istegiyle 0.35'e indi:
    // "sorun barizse guc, biraz daha kisalim."
    //
    // 0.15 alt sinir ve orasi "kisik ekran" degil "kapali ekran" gibi
    // gorunuyor (pati_ekran.hpp).
    //
    // 11.09.2026: kullanicinin istegiyle 0.35 -> 0.25. Gerekce yine
    // "sorun barizse guc, biraz daha kisalim" — 02.09'da 0.45'ten
    // 0.35'e inerken de ayni gerekce vardi.
    //
    // ⚠️ KADEMELI GIDILIYOR, uca atlanmiyor: 0.45 -> 0.35 -> 0.25 ve
    // taban 0.15. Kullanicinin donanim kurali bu. Karanlik gelirse
    // geri alinacak yer burasi — tek satir.
    //
    // ⚠️ Bu da olculmus bir kazanc DEGIL. Arka isik surekli bir yuk,
    // yani taban akimi dusuruyor; brownout'u yapan TEPE akimi
    // dusurdugu iddia edilmiyor.
    // 🔴 BURADAKI DEGER YALNIZCA ILK ANLAR ICIN.
    //
    // Gercek deger NVS'te ve `ayar_baslat()` cok daha sonra kosuyor
    // (bu dosyanin sonlarinda). Arka isik ise gozler acilirken
    // yakiliyor, yani ARADA. O aralikta ne yazarsa o gorunuyor.
    //
    // ⚠️ BU YUZDEN MUHAFAZAKAR: %25. Buraya %100 yazmak, ebeveyn
    // %5 secmis olsa bile her acilista kisa bir TAM PARLAK cakma
    // demekti — karanlik bir odada uyandirici bir sey.
    pati::ekran_parlaklik_ayarla(0.25f);

    // ---- WIFI VERICI GUCU: DENENDI VE GERI ALINDI ------------------------
    //
    // 02.09.2026'da pilde 20 dBm'den 15 dBm'e indirildi. Gerekcesi
    // saglamdi: telsiz gonderirken 250-350 mA cekiyor ve Pati surekli
    // gonderiyor.
    //
    // ❌ BEDELI HEMEN GORULDU: kullanici "modemin dibinde bile zor
    // cekiyor" dedi ve panel 3/4'ten 1/4'e dustu. 3 dB'lik dusus bu
    // kartin anteni icin fazlaymis.
    //
    // Zayif wifi ayrica hedefin TERSINE calisiyor: baglanti kotulesince
    // telsiz daha cok yeniden gonderiyor, yani ortalama akim ARTABILIR.
    //
    // Tekrar denenecekse 18 dBm gibi daha kucuk bir adim mantikli, ve
    // once wifi kapsamasi duzeltilmeli — Pati'nin sinyali zaten dusuk
    // ve bu ayri bir sorun (TESHIS.md'de 10 saniyelik TCP takilmalari).

    // ---- GOZLER: pilde yavas, konusurken daha yavas ---------------------
    //
    // Kullanicinin oncelik sirasi: once cokmeme, sonra SES, sonra
    // gorunum. Ses tavanina DOKUNULMUYOR (0.70'te sabit); pilde feda
    // edilebilir tek yer gozler.
    //
    // 02.09.2026 olcumu: 20 -> 10 fps, cokme arasini ~40 saniyeden
    // ~4,5 dakikaya cikardi. Gerekce ve sayilar pati_gozler.cpp'de.
    //
    // 🔴 BURADA ARTIK BIR CAGRI YOK. Kare hizi kaynaktan bagimsiz hale
    // geldi ve karari gozler kendi iciyor (pati_gozler.cpp ·
    // gozler_hedef_fps). Bir profil secicisi birakmak, ileride birinin
    // "USB'de hizlandiralim" diye geri acmasina davetiye olurdu.

    // ⚠️ LOGDAKI SES TAVANI HESAPLANMIYOR, SORULUYOR.
    //
    // Eskiden burada `pilde ? min(seviye, TAVAN) : seviye` yaziyordu ve
    // 3.5.2'den beri YANLISTI: tavan o surumde iki kaynakta da gecerli
    // oldu (pati_ses.cpp · ses_etkin_seviye), ama bu satir USB'de hala
    // sinirsiz seviye basiyordu. Yani log, kodun yaptigini degil eski
    // halini anlatiyordu — teshiste en pahali yanlis turu.
    //
    // Artik fiilen uygulanan degeri kaynagindan okuyoruz.
    ESP_LOGW(ETIKET, "GUC KAYNAGI: %s · pil %d mV (%%%d) · VIN %d mV · "
                     "ses tavani %.2f · gozler %d fps (tek profil)",
             kaynak == pati::GucKaynagi::Usb   ? "USB/5VIN"
             : kaynak == pati::GucKaynagi::Pil ? "PIL"
                                               : "BILINMIYOR",
             pati::pil_mv(), pati::pil_yuzde(), pati::vin_mv(),
             static_cast<double>(pati::ses_etkin_seviye()),
             pati::gozler_hedef_fps());
}

// Tusa basildi.
//
// TUS GOREVINDEN cagriliyor, yani BLOKLAMAMALI. Yaptigi tek sey bir
// atomik bayrak birakmak; sayfayi goz gorevi ciziyor.
//
// ⚠️ IKI TUS DA AYNI ISI YAPIYOR. Ekranin sagindaki mavi dugmenin G11
// mi G12 mi oldugu olculmedi (pati_tus.hpp). Ikisini de baglamak
// dogru davranisi bugun veriyor; hangisi oldugu seri porttan
// ogrenilince burasi ayrilabilir.
void tusa_basildi(int, bool uzun)
{
    if (uzun) {
        // Uzun basis = "kapat". Geri donmuyor.
        //
        // ⚠️ GERCEK KAPANMA DEGIL, derin uyku — gerekcesi ve bedeli
        // pati_guc.hpp'de. Ozeti: ESP32 kapaliyken hicbir yazilim
        // calismadigi icin cihaz kendini ACAMAZ, o yuzden gerçek
        // kapanma yan düğmeye tek basışla yapılır.
        // Derin uyku ayni tusla geri gelebilmeyi mumkun kiliyor.
        pati::guc_derin_uyku();
    }
    // Guncelleme perdesi aciksa mavi tus BASKA BIR IS yapiyor.
    //
    // Ayni tus, ekranda ne yaziyorsa onu yapmali: ekranda "MAVI TUSA
    // BAS" yaziyorken bilgi sayfasi acmak, cocuga tusun bozuk oldugunu
    // dusundururdu.
    if (pati::gozler_guncelleme_acik()) {
        // Dusuk pilde baslatmiyoruz — ekranda zaten "once sarja tak"
        // yaziyor ve basmanin bir sey yapmamasi o yazinin karsiligi.
        // Gerekce pati_gozler.cpp'de GUNC_EN_AZ_PIL.
        const int y = pati::pil_yuzde();
        const bool pil_zayif = pati::guc_kaynak() != pati::GucKaynagi::Usb
                               && y >= 0 && y < 40;
        if (!pil_zayif) {
            ESP_LOGW(ETIKET, "guncelleme cocugun istegiyle basliyor");
            pati::guncelleme_indir();
        } else {
            ESP_LOGW(ETIKET, "guncelleme istendi ama pil %%%d — reddedildi", y);
        }
        return;
    }

    pati::gozler_bilgi_degistir();
}

void guc_gozcusu(void*)
{
    pati::GucKaynagi onceki = pati::GucKaynagi::Bilinmiyor;
    bool ilk = true;
    std::int64_t son_uyari_us = 0;

    while (true) {
        pati::pil_ornekle();

        const pati::GucKaynagi kaynak = pati::guc_kaynak();

        // ---- GOZ GOREVINE DURUM BILDIR --------------------------------
        //
        // 🔴 GOZ GOREVI ARTIK HICBIR SEY SORMUYOR. Perde kararlari icin
        // guncelleme, ag ve guc durumuna bakiyordu; ikisi KILIT aliyor
        // (ayni kilidi panel de aliyor), biri I2C yapiyor.
        //
        // 02.09.2026'da iki kez goruldu: gozler dondu ve donuk kaldi,
        // sonunda cihaz coktu. Cizim gorevi bekleyebilecegi hicbir sey
        // icermemeli.
        //
        // Burasi zaten 2 saniyede bir donuyor ve bu sorulari sormanin
        // dogru yeri: bu gorev bekleyebilir, goz gorevi bekleyemez.
        {
            const pati::AgDurumu ag = pati::ag_durumu();

            // 🔴 "KURULUM" = AP ACIK, durum makinesinin hali degil.
            // Ikisi ayrisabiliyor (pati_ag.hpp · ag_kurulum_agi_acik)
            // ve ayristigi anda kurulum perdesi ekranda hic
            // gorunmuyordu.
            //
            // "Bagli" de AP acikken false: AP acikken Pati ev aginda
            // sayilmaz, ve o hali kurulum perdesi anlatiyor.
            const bool ap_acik = pati::ag_kurulum_agi_acik();
            pati::gozler_durum_bildir(
                static_cast<int>(pati::guncelleme_durumu()),
                pati::guncelleme_yuzde(),
                pati::guncelleme_yeni_surum(),
                !ap_acik && ag == pati::AgDurumu::Bagli,
                ap_acik,
                pati::pil_yuzde(),
                kaynak == pati::GucKaynagi::Usb, pati::ag_gucu());

            // DNS ele gecirmenin omru AP'nin omrune bagli. Ikisi de
            // fikirsiz (idempotent), yani her turda cagrilmasi guvenli
            // — ve boylece AP ne zaman acilip kapanirsa kapansin
            // captive portal onunla birlikte gelip gidiyor.
            if (ap_acik) {
                pati::panel_dns_baslat();
            } else {
                pati::panel_kurulum_bitti();
            }
        }
        if (ilk || kaynak != onceki) {
            ilk = false;
            onceki = kaynak;
            guc_kipi_uygula(kaynak);
        }

        // ---- DUSUK PIL UYARISI ------------------------------------------
        //
        // NEDEN GEREKLI: cocuk Pati'yi her zaman dolu pille kullanmayacak
        // ve "sarja tak" diye bir sey soylenmezse pilin bittigini ancak
        // Pati sustugunda anlayacak. Uyari, sohbetin ortasinda sessizce
        // olmekten iyi.
        //
        // pil_dusuk() histerezisli ve USB'de her zaman false — yani
        // sarj olurken uyari cikmiyor.
        if (pati::pil_dusuk()) {
            const std::int64_t simdi = esp_timer_get_time();
            if (son_uyari_us == 0 || simdi - son_uyari_us >= UYARI_ARALIK_US) {
                son_uyari_us = simdi;
                pati::gozler_pil_uyarisi(pati::pil_yuzde());
                ESP_LOGW(ETIKET, "DUSUK PIL: %%%d (%d mV) — uyari gosterildi",
                         pati::pil_yuzde(), pati::pil_mv());
            }
        } else {
            // Sarja takildi ya da esigin uzerine cikti: bir dahaki
            // dususte uyari HEMEN ciksin, dakikayi bekletme.
            son_uyari_us = 0;
        }

        vTaskDelay(pdMS_TO_TICKS(GOZCU_ARALIK_MS));
    }
}
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
extern "C" void app_main()
{
    // NVS ilk isimiz: wifi bilgisi ve Pati'nin hafizasi burada duracak.
    // Bozuksa silip yeniden kuruyoruz — cocuk fisi cekince olusan
    // yarim yazmalar burada birikir.
    esp_err_t nvs = nvs_flash_init();
    if (nvs == ESP_ERR_NVS_NO_FREE_PAGES || nvs == ESP_ERR_NVS_NEW_VERSION_FOUND) {
        ESP_LOGW(ETIKET, "NVS bozuk ya da eski, silinip yeniden kuruluyor");
        ESP_ERROR_CHECK(nvs_flash_erase());
        nvs = nvs_flash_init();
    }
    ESP_ERROR_CHECK(nvs);

    // ---- GUC VE I2C -----------------------------------------------------
    //
    // BUNDAN SONRAKI HER SEYDEN ONCE. Mikrofon, hoparlor ve ekranin arka
    // isigi M5PM1'in "L3B" katmanindan besleniyor ve o katman acilista
    // KENDILIGINDEN GELMIYOR — acmazsak ucu birden olu kalir ve hicbiri
    // hata vermez. Gerekce pati_pinler.h'nin basinda.
    if (pati::guc_baslat() != ESP_OK) {
        ESP_LOGE(ETIKET, "guc katmani kurulamadi — mikrofon, hoparlor ve "
                         "ekran arka isigi calismayacak");
    }

    // ---- BEDEN — MOTOR PINLERI MUMKUN OLAN EN ERKEN ANDA ASAGI ----------
    //
    // 🔴 BU SATIR NEDEN TAM BURADA: ESP32 cikislari yazilim kurana kadar
    // HAVADA kaliyor ve gövde takiliysa L9110'un girisleri o sirada
    // belirsiz — yani motorlar acilista kendiliginden donebilir.
    // Pencereyi kapatmanin tek yolu erken kurmak.
    //
    // Donanim kilidinden ONCE, cunku kilit yanlis kartta esp_restart()
    // cagirabiliyor ve o yol motorlari asagi cekmis olarak birakmali.
    //
    // Basarisiz olursa DEVAM EDIYORUZ: bedensiz Pati zaten calisiyor.
    if (pati::beden_baslat() != ESP_OK) {
        ESP_LOGW(ETIKET, "beden katmani kurulamadi — kollar ve tekerlekler "
                         "calismayacak");
    }

    // ---- DONANIM KILIDI -------------------------------------------------
    donanimi_dogrula();

    // Gemini anahtari KENDI NVS bolumunde (bkz. partitions.csv). Ayri
    // durmasinin sebebi tam da yukaridaki satir: bozuk NVS silinip
    // yeniden kuruluyor ve anahtar o silmeden etkilenmemeli.
    //
    // Basarisiz olursa DEVAM EDIYORUZ: sebebi neredeyse kesin olarak
    // eski bolum tablosu ve bunu gorebilmenin tek yolu panelin acilmasi.
    pati::anahtar_baslat();
    pati::guncelleme_baslat();

    ESP_LOGI(ETIKET, "");
    ESP_LOGI(ETIKET, "===== PATI %s =====", pati::guncelleme_surumu());
    ESP_LOGI(ETIKET, "Amac: gercek kartta 'cocuk sustu -> ilk ses' olcumu");
    ESP_LOGI(ETIKET, "Kriter: <=1500 ms gecer (PLAN.md)");
    ESP_LOGI(ETIKET, "");

    karti_yaz();

    // Olcum matematigi PC ile ayni mi? Bunu HER ACILISTA siniyoruz.
    //
    // Neden acilista: Asama 2'nin butun amaci bir sayi uretmek ve o sayiyi
    // PC'de olculen 1325 ms ile karsilastirmak. Matematik farkliysa
    // karsilastirma anlamsiz olur — ve bu, sayilara bakip "gecti" dedikten
    // SONRA fark edilecek bir hata olurdu.
    pati::olcum_baslat();
    pati::oz_test();

    istemciyi_dene();
    ses_hattini_dene();

    // Wifi. Baglanamazsa DEVAM ETMIYORUZ: Asama 2'nin tek isi gecikme
    // olcmek ve baglanti olmadan olculecek bir sey yok. Sessizce devam
    // etmek, sonra "neden veri gelmiyor" diye aramaya yol aciyor.
    // HAFIZA sohbetten ONCE okunmali: sistem promptu onu iceriyor.
    // Sonra okunursa robot ilk oturumda cocugu tanimiyor gibi davranir.
    if (pati::hafiza_baslat() != ESP_OK) {
        ESP_LOGW(ETIKET, "hafiza okunamadi — Pati cocugu bastan taniyacak");
    }
    pati::hafiza_oturum_sayaci();

    // GOZLER wifi'den ONCE aciliyor.
    //
    // Wifi'ye baglanmak saniyeler suruyor. Ekran o sure boyunca siyah
    // kalirsa "acilmadi" saniiliyor — cocuk icin de fisi takar takmaz
    // bir hayat belirtisi olmasi gerekiyor.
    //
    // Basarisiz olsa bile DEVAM EDIYORUZ: ekransiz Pati konusabilir.
    // Yuzu olmayan robot, sessiz robottan iyidir.
    //
    // ⚠️ ONCEDEN BURADA BIR AYAR VARDI (PATI_EKRAN_VAR) VE KALDIRILDI.
    //
    // Onceki kartta ekran disaridan lehimlenen bir moduldu ve VARLIGI
    // KODDAN ANLASILAMIYORDU: SPI yolu tek yonlu kuruluyor, panel hic
    // bagli olmasa bile esp_lcd hatasiz aciliyor ve gozler_baslat()
    // ESP_OK donuyordu. Olu bir modulle saatlerce tam olarak boyle
    // gorundu; o yuzden "ekran takili mi" diye SORULMASI gerekiyordu.
    //
    // StickS3'te ekran govdenin icinde ve sokulemiyor. Soru anlamsiz
    // hale geldi, ayar da kaldirildi — cevabi degismeyecek bir soruyu
    // ayar olarak birakmak, bir gun yanlis cevaplanmasini beklemektir.
    //
    // Bedeli hala gercek (23.08.2026, onceki kartta olculdu: kare
    // ortancasi 114 ms, 50 ms'lik butce) ama artik bir secim degil:
    // ekran orada ve cocuk yuze bakiyor.
    if (pati::gozler_baslat() != ESP_OK) {
        ESP_LOGW(ETIKET, "ekran acilmadi — Pati yuzsuz devam ediyor");
    } else {
        pati::gozler_bos();
    }

    // GUC GOZCUSU — TAM BURADA baslamali.
    //
    // Gozler acildi (yani kismasi anlamli oldu) ve asagidaki ag beklemesi
    // HENUZ BASLAMADI. Bir satir asagi konsa, wifi baglanana kadar gecen
    // saniyelerde pil kipi yine uygulanmamis olurdu — duzeltmeye
    // calistigimiz kusurun ta kendisi (gerekce gorevin basinda).
    if (xTaskCreate(guc_gozcusu, "pati_guc", 3072, nullptr, 3, nullptr)
        != pdPASS) {
        // Olumcul degil: guc kipi uygulanmaz, Pati calisir. Ama pilde
        // daha sik coker, o yuzden sessiz gecilmiyor.
        ESP_LOGE(ETIKET, "guc gozcusu baslatilamadi — pil kipi ve dusuk "
                         "pil uyarisi CALISMAYACAK");
    }

    // TUSLAR. Gozlerden sonra, agdan once: bilgi sayfasi wifi
    // baglanmasini beklemek zorunda degil — baglanti YOKKEN de acilip
    // "WiFi yok" gostermesi dogru davranis, cunku cocugun sordugu soru
    // tam da bu olabilir.
    if (pati::tus_baslat(tusa_basildi) != ESP_OK) {
        // Olumcul degil: tussuz Pati konusabiliyor, sadece bilgi
        // sayfasi acilamaz.
        ESP_LOGW(ETIKET, "tuslar kurulamadi — bilgi sayfasi acilamayacak");
    }

    // AG — artik gomulu wifi yok (§4.3). Kayitli ag varsa baglaniyor,
    // yoksa kendi agini yayinlayip captive portal aciyor.
    //
    // BLOKLAMIYOR: baglanma denemeleri saniyeler suruyor ve o sure
    // boyunca gozler olu kalmamali.
    pati::ayar_baslat();

    // Calma hizi ancak AYARLAR OKUNDUKTAN sonra kurulabiliyor:
    // hoparlor_baslat() bundan once kosuyor ve NVS'teki degeri henuz
    // bilmiyor. Pati'nin afacan sesi buna bagli — bkz. pati_ses.hpp.
    pati::hoparlor_hiz_ayarla(pati::ayar_hiz());

    // Ekran parlakligi da ayni sebeple burada: yukaridaki cagri yalnizca
    // acilisin ilk anlarini kapsiyordu, ebeveynin sectigi deger ancak
    // simdi biliniyor.
    pati::ekran_parlaklik_ayarla(
        static_cast<float>(pati::ayar_parlaklik()) / 100.0f);

    pati::kullanim_baslat();
    if (pati::ag_baslat() != ESP_OK) {
        ESP_LOGE(ETIKET, "ag katmani baslatilamadi. Sebep yukarida.");
        bekle_ve_dur();
        return;
    }

    // PANEL her iki modda da aciliyor: kurulum modunda ebeveyn wifi
    // bilgisini girmek icin, bagliyken ayarlar icin.
    if (pati::panel_baslat() != ESP_OK) {
        ESP_LOGW(ETIKET, "panel acilmadi — ayarlar telefondan yapilamaz");
    }

    // ---- GERI ALMAYI IPTAL ET -------------------------------------------
    //
    // Yeni bir yapi OTA ile geldiyse "denemede" (PENDING_VERIFY) aciliyor
    // ve burasi cagrilmadan yeniden baslarsa onyukleyici ESKI yapiya
    // donuyor (CONFIG_BOOTLOADER_APP_ROLLBACK_ENABLE).
    //
    // NEDEN TAM BURADA:
    //
    //   ONCESI OLMAZ. Buraya kadar gelmek NVS, ekran, ses hatti, ag
    //   katmani ve HTTP sunucusunun tamaminin ayaga kalktigini
    //   kanitliyor. Daha erken onaylamak, bu yollardan birini kiran bir
    //   yapiyi saglam ilan etmek olurdu.
    //
    //   SONRASI DA OLMAZ. Bir sonraki adim wifi bekleme dongusu ve orada
    //   SURESIZ kalinabiliyor: robot kurulum modundaysa anne wifi
    //   bilgisini girene kadar bekliyor. Onayi oraya koysaydik, kurulum
    //   sirasinda fisi cekilen robot bir onceki surume donerdi — ve
    //   fisin cekilmesi bu robotun BEKLENEN kapanma bicimi.
    //
    // Sohbetin baslamasi onaya dahil DEGIL: anahtar yanlissa sohbet
    // acilmiyor ama bu firmware'in degil, girilen anahtarin sorunu.
    // Geri almak onu duzeltmezdi.
    pati::guncelleme_onayla();
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

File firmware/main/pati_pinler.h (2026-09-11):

// Pati donanim tanimlari — M5Stack StickS3 (SKU K150)
//
// BU DOSYA TEK KAYNAK. Pin numarasi baska hicbir yere yazilmayacak;
// iki yerde iki numara olursa hangisinin dogru oldugu anlasilmiyor.
//
// Tablo docs.m5stack.com/en/core/StickS3 icindeki PinMap bolumunden
// satir satir alindi (23.08.2026). Onceki karttan (ESP32-S3-DevKitC
// klonu + INMP441 + MAX98357) farkli olarak bu kartta hicbir sey
// lehimlenmiyor: mikrofon, hoparlor, ekran, pil ve butonlar govdenin
// icinde ve sabit.
//
// ⚠️ ONCEKI DONANIMIN PIN HARITASI ICIN: git show v2.2.8-devkit:firmware/main/pati_pinler.h

#pragma once

#include <driver/gpio.h>

// ---------------------------------------------------------------------------
// 🔴 EN ONEMLI SEY: L3B GUC KATMANI
// ---------------------------------------------------------------------------
//
// Mikrofon, ES8311 kodek ve LCD arka isigi dogrudan ESP32'den DEGIL, M5PM1
// guc yonetim yongasinin actigi "L3B" katmanindan besleniyor. Ve L3B
// acilista KENDILIGINDEN GELMIYOR.
// Hoparlor amfisi AW8737A ise VBUS_L0'dan beslenir (K150 V0.6, s.3).
// Kodek kapaliyken ses gelmemesi, amfinin de L3B'de oldugu anlamina gelmez.
//
// M5Stack'in belgesi (arduino/m5sticks3/m5pm1, "Multi-Level Power
// Switch Design"): "After the M5PM1 starts up and powers on, L0, L1 and
// L2 will be automatically enabled. During the M5Unified initialization
// process, L3A and L3B will be further enabled."
//
// Yani L3B'yi Arduino tarafinda M5Unified aciyor. Biz ciplak ESP-IDF
// kullaniyoruz, M5Unified yok — ACMAZSAK KENDIMIZ ACMAK ZORUNDAYIZ.
//
// Acmazsak ne olur: ekran siyah, mikrofon sagir, hoparlor sessiz. Ucu
// birden. Ve hicbiri hata vermez — I2S kanali sorunsuz acilir, SPI
// sorunsuz yazar, kod her yerde ESP_OK doner. Yani tipatip bir YAZILIM
// hatasi gibi gorunur ve gunlerce orada aranir.
//
// Onceki kartta olu ekran icin harcanan gunlerin sebebi buna cok
// benziyordu; bu sefer sebep belgelenmis halde duruyor.
//
// Kod: pati_guc.cpp · guc_baslat()

// ---------------------------------------------------------------------------
// I2C — UC AYGIT AYNI HATTI PAYLASIYOR
// ---------------------------------------------------------------------------
//
// Tek hat, uc adres. Hepsi ayni iki pinde:
//
//   0x18  ES8311   ses kodegi (mikrofon + hoparlor)
//   0x68  BMI270   6 eksen IMU        (Pati kullanmiyor)
//   0x6E  M5PM1    guc yonetimi       (L3B ve amfi anahtari)
//
// ES8311'in burada olmasi onemli: ses yolunun YAPILANDIRMASI I2C'den,
// VERISI I2S'ten gidiyor. Ikisi ayri hat, ikisi de kurulmali.

#define PATI_I2C_SCL GPIO_NUM_48
#define PATI_I2C_SDA GPIO_NUM_47

// 🔴 100 kHz, 400 DEGIL — GERCEK KARTTA OLCULDU (23.08.2026).
//
// Once 400 kHz yazilmisti ("400 kHz standart, herkes kullaniyor") ve
// kart gelince su cikti: M5PM1 ADRESINE cevap veriyor (yoklama geciyor)
// ama ilk register okumasi NACK yiyor. IDF'in hatasi
// ESP_ERR_INVALID_STATE — "islem tamamlanmadi", yani NACK
// (esp_driver_i2c/i2c_master.c:727).
//
// Sonuc zinciri sessizdi ve tam da korktugumuz gibiydi:
//   M5PM1 yaziamiyor -> L3B acilmiyor -> mikrofon, hoparlor ve ekran
//   arka isigi beslenmiyor -> ES8311 0x18'de cevap vermiyor -> "yanlis
//   donanim" sanildi. Ekran simsiyahti.
//
// Sebep M5PM1'in kendi surucusunde yaziyor (github.com/m5stack/M5PM1,
// M5PM1.cpp): `_requestedSpeed = M5PM1_I2C_FREQ_100K` ve
// `_i2cConfig.speed400k = false`. Yani yonga 100 kHz'de baslıyor;
// 400 kHz AYRICA ACILMASI gereken bir kip.
//
// ES8311 zaten 100 kHz'i destekliyor ve hattaki tek is acilistaki
// register kurulumu — birkac milisaniye fark eder, hicbir sey
// kaybetmiyoruz.
#define PATI_I2C_HZ (100 * 1000)

#define PATI_ADR_ES8311 0x18
#define PATI_ADR_M5PM1  0x6E

// M5PM1 register haritasi — M5PM1 surucu kutuphanesinin basligindan
// (github.com/m5stack/M5PM1, src/M5PM1.h). Kutuphaneyi bagimlilik
// olarak almiyoruz: dort register yazmak icin Arduino katmani ve eski
// I2C surucusu (espressif/i2c_bus) getirmeye degmez.
#define PATI_PM1_GPIO_MODE  0x10  // [4:0] yon      1 = cikis
#define PATI_PM1_GPIO_OUT   0x11  // [4:0] seviye   1 = yuksek
#define PATI_PM1_GPIO_DRV   0x13  // [4:0] surus    0 = push-pull
#define PATI_PM1_GPIO_FUNC0 0x16  // pin basina 2 bit, 0b00 = GPIO
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

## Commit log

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2026-07-31 Move the Gemini key to the device and add panel updates
    The key was compiled in (CONFIG_PATI_GEMINI_API_KEY). That could not
    survive over-the-air updates: shipping pati.bin to a release would ship
    the key with it and bill whoever owns it. The Kconfig entry is removed
    rather than defaulted to empty, so it cannot be filled in and published
    by accident.
    The key now lives in its own NVS partition and is entered from the
    panel. Separate from the main partition because a factory reset must not
    clear it (it is setup information, not the child's data) and because the
    expected shutdown here is a power cut, which can corrupt NVS badly enough
    that app_main erases it.
    Google's rejection is classified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
    [partitions.csv]
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2026-07-31 Fix two faults found on the board, not on the bench
    Both were the panel reporting something the robot was not doing, which
    is the failure this project keeps hitting.
    The key check ran from app_main at boot and failed every time with
    mbedtls -0x0050, NET_CONN_RESET. The key was fine: the same key opened a
    Gemini session twenty seconds later, and the clock was already set. The
    cause was where it ran — app_main shares CPU 0 with the eye task, which
    overruns its frame budget and starves the core, so the TLS handshake
    timed out and the peer closed it. The same logs show the watchdog firing
    for the same reason. The panel then said "cannot reach Google" while the
    robot was talking, which would s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
    [app_main.cpp]
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2026-08-23 Play the whole audio chunk, which the volume path silently truncated
    hoparlor_yaz scaled into a 1024-sample buffer, clamped with std::min,
    and threw the rest away. The caller ignores the return value, so the
    loss was recorded nowhere.
    1024 samples is 42 ms at 24 kHz. The comment beside it said "Gemini
    sends ~20-40 ms", which is the sound of a bound that was measured once
    and never crossed since. Chunks a little longer lost their tail, and
    that is what the small gaps in Pati's speech were.
    The path is not an edge case: the default volume is 0.85, so every
    chunk goes through it. Measurements were taken at full volume, where
    the branch is skipped entirely -- which is why nothing caught this.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
    [pati_ses.cpp]
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2026-08-23 Size the speaker buffer to Gemini's chunk length, not to a guess
    Measured on the board, three turns: 24 chunks / 4820 ms, 27 / 7600,
    40 / 11160 -- so Gemini delivers audio in 200-280 ms blocks. The DMA
    buffer held 200 ms. One chunk filled the whole buffer, which left no
    margin at all: a single late chunk drained it and the gap was audible.
    Turn 1 showed exactly that -- 404 ms between chunks, 262 ms of silence.
    32 x 512 = 683 ms of source audio, roughly three chunks of slack.
    This costs nothing elsewhere. The buffer is a ceiling rather than a
    fixed wait, so the first sound is not delayed; and barge-in still cuts
    instantly because hoparlor_temizle() disables and re-enables the
    channel, which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
    [pati_ses.cpp]
2026-08-23 Skip the glow pixels the opaque eye is about to overwrite
    Each row drew three glow layers, then the eye, then the highlight. The
    glow layers covered the eye's own span too -- and the eye is drawn with
    alpha 1.0, so satir_karistir assigns directly and throws all of it
    away. Thousands of pixels per frame were blended three times and then
    discarded.
    satira_yuvarlak is split in two: satir_araligi computes the row span,
    the fill uses it. That makes the eye's span knowable before the glow is
    drawn, which is the whole point of the split.
    Only fully covered pixels are skipped. The partially covered ones at
    the edge (coverage < 1) really do blend with what is underneath, and
    skipping those would le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
    [pati_gozler.cpp]
2026-08-23 Make the screen's presence a setting, because the code cannot detect it
    gozler_baslat() returns ESP_OK with no panel attached. The SPI bus is
    configured write-only, so esp_lcd opens cleanly against nothing at all
    -- which is how a dead module looked healthy for hours. The "carry on
    if it fails" guard in app_main never fired, because nothing failed.
    So it has to be told. PATI_EKRAN_VAR defaults to y, since the screen is
    part of the finished robot; turning it off skips the eye task entirely
    and hands that time back to audio. Flipping it is a release, not a trip
    to the workbench.
    The skipped-frame warning now prints the breakdown too. It used to say
    only that the budget was blown, which made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
    [app_main.cpp]
2026-08-23 Raise the volume above unity, which needed a limiter to be safe at all
    The ceiling was 1.00 and had to be: the scaling path cast straight to
    int16 with no clamp, so anything above unity produced a float past
    32767 and overflowed. An overflowed sample flips sign at full scale --
    "turning it up" meant a crack in the speaker, not a louder robot.
    yumusak_sinirla shapes instead. Below 28000 (~0.85 full scale) it does
    nothing, so most of the speech passes untouched; above it the curve
    approaches 32767 asymptotically and never reaches it. Rounding the peak
    rather than flattening it matters here: flat-topped clipping is heard as
    a rasp, which is the worst kind of distortion to put in a child's room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
    [pati_ses.cpp]
2026-08-23 Move Pati to the StickS3, where one I2S clock has to serve both directions
    The robot is no longer thirteen soldered wires on a devkit. It is one
    M5Stack StickS3 with the microphone, speaker, display and battery
    already inside. The devkit is kept, not deleted: branch `devkit`, tag
    `v2.2.8-devkit`, and its built binary in the v2.2.8 release.
    Most of the code did not care. The conversation, the personality, the
    memory, the parent panel, the captive portal, OTA and the eye engine
    carried over untouched. Three things did care.
    THE CLOCK. The microphone and speaker are both inside one ES8311 on one
    I2S bus, so they share a sample rate. The old board ran them at 16 and
    24 kHz on separate peripher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
    [partitions.csv]
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2026-08-23 Clear out what was left describing a robot that no longer exists
    The firmware moved to the StickS3 but the rest of the repository still
    described the devkit: a soldering guide, a wiring diagram, printed
    enclosure parts, a design studio drawing a two-part robot around a 50 mm
    speaker, and comments saying the screen is square.
    None of it is deleted. It describes hardware that still exists on the
    `devkit` branch, so it lives there instead of misleading anyone here.
    The assembly guide went across with the work that was in progress on it.
    What was converted rather than archived:
    THE STUDIO still answers a question that matters more now, not less —
    "do the eyes look right at actual size?" The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
    [base.stl, body.stl, head-lower.stl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]
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2026-08-23 Size the audio buffer against the RAM that is actually left
    idf.py size says 184 KB of internal RAM remains after static allocation,
    and that is what WiFi, TLS, the websocket, task stacks and the display
    strip buffers all draw from at runtime. The buffer was asking for 98 KB
    of it, because full duplex forces TX and RX to share one configuration
    and every millisecond is paid for twice.
    The two failures are not equally bad. Too large and the allocation still
    succeeds, then WiFi cannot find memory and Pati never connects at all -
    nobody would look for that in the audio buffer. Too small and the worst
    case is a short stutter, fixed by one constant, with the place to look
    named in the log.
    So 3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
    [pati_guc.cpp, pati_ses.cpp]
2026-09-01 Talk to the power chip at the speed it actually starts up at
    The board arrived and nothing came up: black screen, no codec, and the
    hardware guard declaring the wrong board. All four symptoms had one
    cause. The M5PM1 answers its address at 400 kHz - the probe passed -
    but NACKs the first register transaction, so L3B never switched on, and
    L3B is what powers the microphone, the speaker and the display
    backlight. With no power the ES8311 cannot answer either, which is
    exactly what "wrong hardware" looks like from the outside.
    M5Stack own driver says it plainly: _requestedSpeed starts at
    M5PM1_I2C_FREQ_100K and speed400k is false. 400 kHz is a mode you have
    to enable, not a default. The ES8311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
    [app_main.cpp, pati_guc.cpp, pati_pinler.h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]
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2026-09-02 Write down what battery mode is for, and give it a way to count itself
    Pati still restarts on battery, the moment it starts speaking. USB is
    fine. Two attempts at it - dropping the volume and dimming the screen -
    were reasoned rather than measured, and neither worked.
    PIL.md carries the open work: the goal, the order things may be
    sacrificed in (the volume floor is not negotiable), what has been tried
    and what it cost, the untried candidates with their trade-offs, and the
    A/B method. TESHIS.md is for what is solved; this is for what is not.
    The eye task draws for 24-30 ms of every 50 ms frame, which is over half
    a core, continuously. On battery it now runs at 10 fps instead of 20.
    That is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
    [app_main.cpp, pati_ekran.cpp, pati_gozler.cpp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]
2026-09-02 Ask for the charger instead of just going quiet
    Three things, all pointing at the same night's measurement.
    The eyes at 10 fps on battery turned out to be real: nine minutes on
    the desk gave two crashes instead of one every 20-60 seconds, and at a
    LOWER voltage than the baseline. So the drawing load matters, and the
    same recording showed two more things worth acting on.
    First, a genuine defect. The power mode was applied from the main
    loop, and that loop only starts after wifi connects and the first
    Gemini session opens. So for six seconds after every brownout — while
    the radio is drawing its worst and TLS is chewing the CPU — the eyes
    were still running at full speed. A wifi hiccup wo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
    [app_main.cpp, pati_gozler.cpp, pati_guc.cpp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]
2026-09-02 Give the child two buttons that do what a child would expect
    Both gestures are single actions now. The M5PM1's own shutdown is a
    double click and no child is going to land that; the side button is
    also stiff, so holding it down was rejected too. Side button: one tap
    off, one tap on. Blue button: short press shows battery and wifi, long
    press sleeps.
    Making the side button work meant correcting pati_pinler.h, which had
    claimed for months that the button "is invisible to the ESP32 and
    cannot be changed from software." Both halves were wrong. Its state
    reads over I2C at 0x48 and its timings configure at 0x49. That line
    had been written without measuring and it hid a capability.
    The download-m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
    [app_main.cpp, pati_ekran.cpp, pati_gozler.cpp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]
2026-09-02 Let Pati say why it is quiet, and offer its own update
    Two overlays, both drawn in place of the eyes.
    Without wifi Pati simply did not answer. The eyes kept blinking
    normally, so from the child's side the robot was just broken. Now a
    wifi symbol appears and its arcs pulse downward — signal arriving,
    not being sent — until the network comes back. A silent robot should
    say why it is silent.
    The update check only ever ran when a parent opened the panel and
    asked for it. Children do not open panels and parents do not open them
    daily, so devices sat on old builds. It runs at boot now, and if there
    is something new the screen says so and points at the blue button. One
    press starts it and the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
    [app_main.cpp, pati_gozler.cpp]
2026-09-02 Stop guessing about current and go look at the hardware limits
    Two days of measurement kept pointing at "brownout" and I kept trying
    to reduce current without once asking what the brownout threshold
    actually was. It turns out to be the one thing that was already
    correct: on the S3 the levels run the opposite way to the ESP32, and
    LVL_SEL_7 is the most tolerant setting at 2.44V, not the most
    sensitive. Pati was already there.
    A forum comment said level 7 meant 2.98V. It was talking about the
    ESP32. Had I trusted it I would have moved the threshold the wrong
    way and made things worse. The number in this commit comes from
    esp-idf's own Kconfig for the S3.
    That leaves a fact worth more than th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
    [app_main.cpp, pati_gozler.cpp, pati_guc.cpp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]
2026-09-02 Put the radio back where it was
    The wifi transmit reduction lasted about ten minutes. Dropping 20dBm
    to 15dBm looked like the biggest untried saving — the radio pulls
    250-350mA while transmitting and Pati transmits continuously — but
    the panel went from 3/4 bars to 1/4 and the owner said it was
    struggling right next to the router. Three decibels is too much for
    this antenna.
    It also works against itself: a weak link means more retransmits, so
    average current can go up rather than down. If it is tried again the
    step should be smaller, and the coverage problem should be fixed
    first — Pati's signal was already poor and that is its own open
    issue.
    Everything else in the power package sta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
    [app_main.cpp]
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2026-09-05 Learn to suspect the quota before suspecting the robot
    Pati stopped answering. Everything on the device looked healthy — mic
    working, audio uploading, websocket open, no errors, and Gemini even
    transcribing the child correctly. So the search went to the device and
    stayed there for hours.
    It was the Live API quota. It is per-minute, and when it runs out the
    server does not always say so: it closes with 1011 "Internal error
    occurred." Worse, it feeds itself — the close triggers a reconnect,
    every reconnect spends quota, and the quota never recovers.
    Two ways of ruling it out were tried and both were wrong. "If the
    quota were gone the transcripts would stop too" — they don't, input
    tran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
    [pati_ses.cpp]
2026-09-05 Keep only what today actually proved
    Pati went silent and the cause turned out to be the Live API quota,
    not the device. Along the way I changed three things to fix a problem
    that did not exist: I sent VAD sensitivity that had never been sent,
    filled in commit_audio so the device would close its own turns, and
    made the mic mute itself during silence.
    Every one of those has a real argument behind it. None of them could
    be measured, because the quota was empty during every single test.
    And Pati was talking fine without them the day before.
    So they come out. Leaving three unverified behaviour changes in place
    would mean that tomorrow, when the quota refills, "did one of these
    break it?" becom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
    [app_main.cpp, pati_panel.cpp]
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2026-09-06 Motor PWM 20 kHz -> 5 kHz: sürücü o hızda anahtarlayamıyordu
    Servolar oynuyordu, motorlar hiç oynamıyordu. Belirti tam bir kablo
    hatası gibi görünüyordu; ölçüm başka yeri gösterdi.
    Gerçek kartta ölçüldü (beden takılı, tekerlekler sökülü, pil %41):
    panel -> /api/beden POST {"tamam":true}
    karıştırma + hız tavanı /api/durum -> beden.sol=60 sag=-60
    %60 duty @ 20 kHz DÖNMEDİ
    %100 duty @ 20 kHz DÖNDÜ
    Ayırt eden şey %100: orada duty 1023/1024, yani anahtarlama neredeyse
    hiç yok, çıkış sürekli DC. Kırpılmış her duty'de L9110'un kenarları
    yetişmiyor — bipolar sürücü, üzerinde ~1 V düşüyor, rahat ç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
    [pati_beden.cpp]
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2026-09-06 Pati kendi kararıyla döner, kendi kararıyla ilerlemez
    Tekerlekler Pati'nin kendi kararına açıldı: konuşurken arada
    kendiliğinden kıpırdıyor ve çocuk "dans et" deyince yapıyor. Panelden
    kapatılabiliyor, varsayılan açık.
    Eski kural "tekerlekler asla özerk değil" diyordu ve yanlış yerde
    duruyordu: yasaklanması gereken tekerlek değil, YER DEĞİŞTİRMEYDİ.
    Uçurum sensörü olmayan bir robot ilerlediği sürece eninde sonunda
    masadan düşer.
    Bu yüzden özerkliğin tamamı tek bir sayıyla anlatılıyor:
    sol = +teker sag = -teker
    İki tekerlek her zaman ters yönde, yani yer değiştirme sıfır. Bu bir
    yorumdaki uyarı değil, tipin kendisi — jest tab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
    [pati_beden.cpp, pati_panel.cpp]
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2026-09-09 Yeniden bağlanma: start() bağlandı demek değil
    GERÇEK LOGDAN ÇIKTI (usb-2026-09-09-reset.log): 128223 ve 138403
    ms'de yeniden bağlanma girişimleri var, ikisi de 22 ms sonra
    "başarılı" yazılıyor, arada TLS zaman aşımı geliyor ve sonraki girişim
    yine deneme 1.
    Sebep: istemcinin start() işlevi yalnızca WebSocket görevini başlatıp
    hemen dönüyor; sunucunun hazır oluşu sonraki setupComplete ile
    bildiriliyor. Toparlama kodu erken başarıda sayacı sıfırlıyordu, yani
    asenkron bağlantı hatalarında ARTAN BEKLEME HİÇ ÇALIŞMIYORDU. Bu tam
    da CLAUDE.md'nin uyardığı kota ölüm sarmalı: her başarısız deneme
    sayacı sıfırlar, Pati sunucuya saniyede onlarca el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
    [app_main.cpp]
2026-09-11 Guc profilini birlestir ve konusma basina rampa koy
    Pil/sarj ayrimi kaldirildi. Dayandigi varsayim ("USB'de akim bol")
    11.09.2026'da olcumle coktu: ayni kartta USB'de dolu pille (4048 mV),
    pilde (3950 mV) ve tam silme + temiz yuklemeden sonra — ucunde de
    konusurken brownout. Gozler artik her kaynakta 10 fps, konusurken 5.
    gozler_pil_kipi() kaldirildi; profil secicisi birakmak ayrimi geri
    acmaya davetiye olurdu.
    Konusma basinda 80 ms'lik rampa eklendi. Cikis sessizlikten tam
    seviyeye bir anda atliyordu ve olculen butun brownout'lar tam o anda
    oluyordu. Motorlardaki kuralin ayni fizigi; hoparlore uygulanmamisti.
    Rampa cikis ornegi basina ilerliyor, cagri basina degil — yoksa dilim
    boyutun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
    [app_main.cpp, pati_gozler.cpp, pati_guc.cpp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]
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2026-09-12 Dinlenme konumu araligin ortasi olsun
    Kullanicinin istegi: "dinlenme derecesi min ile maks toplami bolu 2
    olsun — sol kol 0-70 ise 35, sag 0-100 ise 50."
    Oncesinde dinlenme sabit %0 idi ve kol_hedef_yaz onu araligin alt
    ucuna kirpiyordu; dinlenme ile mekanik alt sinir ayni seydi ve
    ayrilamiyordu. Orta nokta ayrica en guvenli yer: kol iki ucta da bir
    seye degebiliyor, ortada ikisinden de uzakta.
    Tek kaynak kol_dinlenme(). Uc cagri yeri (beden takildi, kol kipi
    kapatildi, konusma sonu) ve jest tablosundaki 0 da oraya baglandi —
    yoksa konusma sonunda kol ortaya, jest sonunda alt uca giderdi.
    ⚠️ Jest tablosu DEGISTIRILMEDI: sabitler konak testinin taradigi veri
    ve orada 0 hala 0. Cevi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
    [pati_beden.cpp]
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2026-09-12 Konusma basindaki selam akan jesti ezmesin
    Kullanicinin raporu: "dans et diyorum, Pati evet dans ediyorum diyor ama
    sadece dc motoru saga ceviriyor, 1 kere sadece saga donuyor."
    Sebep beden_konusma_bildir(true): konusma basladiginda KOSULSUZ olarak
    g_jest_istek'e "selam" yaziyordu. Jest baslatma blogu her istegi
    ONCELIKLI sayiyor (cocugun dugmesi beklememeli), yani akan jestin
    uzerine yaziliyordu.
    Sira soyle isliyordu:
    1. model araci cagiriyor (hareket: dans) -> beden_jest("dans")
    2. dans basliyor, ilk donus karesi (300 ms) doniyor
    3. modelin sesi geliyor -> beden_konusma_bildir(true) -> "selam"
    4. dans eziliyor, geriye bir sag donus + el sallama kaliyor
    BELIRTISI TAM BIR "JEST T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
    [pati_beden.cpp]
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2026-09-12 Tekerlek jesti sureyi degil JEST sayisini beklesin
    Kullanici: "neredeyse her konusmasinda saga sola donuyor... enerjik
    eglenceli bir robot olsun dedim ama her cevap verirken ayni hareketi
    yapsin, saga sola donsun demedim."
    Hesabim aritmetik olarak dogruydu (~10,8 sn) ama bir seyi atlamisim:
    BEKLEME SURESI PATI SUSARKEN DE ISLIYOR, oysa jest ancak KONUSURKEN
    baslayabiliyor. Cocuk konusurken ve model dusunurken gecen sure sayaci
    dolduruyor, Pati agzini actigi anda tekerlek kurasi zaten hazir
    oluyordu. Yani sinir fiilen "her cevapta bir" haline geliyordu.
    Sayac artik JEST sayiyor (TEKER_JEST_ARASI = 6). Jestler yalnizca
    konusurken olusuyor, yani sayac sessizlikte DOLMUYOR; aradaki sessizlik
    n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
    [pati_beden.cpp]
2026-09-12 Donus jestlerine cesitlilik: aynalama + iki asimetrik ritim
    Kullanici: "cesitlilik ekleyebilirsin bence, sarhos teker sayesinde
    ileri gitme sorunumuz bitti, cocuk bence masanin dibinde kullanmaz."
    ILERI HAREKET EKLENMEDI ve gerekcesi kaymadan bagimsiz: cozulen sey
    birkac milimetrelik ISTEMSIZ surunmeydi, kasitli yol almak santimetre
    ve bilerek. Sarhos teker yuvarlanmayi KOLAYLASTIRIYOR, guvenli hale
    getirmiyor. "Cocuk masanin dibinde kullanmaz" da tam olarak o kuralin
    var olma sebebi - varsaymak zorunda kalmayalim diye. sol+sag==0 duruyor.
    ASIL BULGU: cesitlilik ileri hareket GEREKTIRMIYOR, yanlis yerde
    aranmis. Net donusun sifir olmasi "simetrik olmak" demek degil;
    sifirlanmasi gereken se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
    [pati_beden.cpp]
2026-09-12 Ileri/geri yonu panelden ters cevrilebilsin; hiz siniri kalici olsun
    Kullanicinin olcumu (13.09.2026): powerbank'li govdede cubugu ileri
    itince Pati GERI gidiyor, geri cekince ileri. AMA SAGA-SOLA DONUS
    DOGRU.
    O ayrinti teshisin kendisi. "Iki motor da ters bagli" olsaydi donus de
    ters olurdu (surus_karistir'da donus iki tekerlegin FARKINDAN geliyor).
    Ileri/geri ters + donus dogru, ancak iki motor HEM ters HEM de
    kanallari caprazlanmis baglandiginda cikiyor: donus iki kez terslenip
    duzeliyor, ileri/geri bir kez terslenip kaliyor.
    Yazilimdaki karsiligi tek islem: joystick'in y'sini ters cevirmek.
    Donus x'ten geliyor, yani ayar ona HIC dokunmuyor - kullanicinin
    "sag sol dogru" olcumu korunuyo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
    [pati_beden.cpp, pati_panel.cpp]
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2026-09-12 Sag/sol yonunu ters cevirme ayari — ileri/geri ayarinin ikizi
    Kullanici: "ileri/geri harika calisiyor, simdi ihtiyacim yok ama belki
    ileride olur diye sagi solu ters cevir de ekler misin, ileri geri
    ekledigin gibi ekle."
    Ayni desen, ayni bogaz (beden_surus, karistirmadan once), ayni kalici
    bolum. Tek fark cevrilen eksen: y yerine x.
    IKISI BIRBIRINDEN BAGIMSIZ ve bu bilincli. Uc ayri hal mumkun:
    - iki motor da ters, kanallar duz -> ileri/geri ters, donus ters
    - kanallar capraz, yonler duz -> ileri/geri dogru, donus ters
    - iki motor ters VE kanallar capraz -> ileri/geri ters, donus dogru
    Ucuncusu bu govdede olculdu (3.5.28). Iki ayri anahtar uc halin ucunu
    de anlatiyor; tek ana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
    [pati_beden.cpp, pati_panel.cpp]
2026-09-12 Ses seviyesi ve parlaklik kalici bolume; dokunmatikte dugmeler
    Kullanicinin istegi: "fabrika ayarlarina don'e bassam da yaptigim
    ayar kalsin." Ikisi de `anahtar` bolumune tasindi.
    Ses tarafinda daha buyuk bir kusur cikti: seviye NVS'te HIC
    saklanmiyordu, yalnizca RAM'deydi ve her acilista tavana donuyordu.
    Sifirlamaya gerek yoktu, fisi cekmek yetiyordu. Aylarca gorulmemesinin
    sebebi de brownout: Pati zaten kendiliginden yeniden basladigi icin
    ayar rastgele araliklarla kayboluyor gibi gorunuyordu.
    Parlakligin eski normal-NVS kaydi acilista bir kez tasinip
    kaynagindan siliniyor; bir degerin iki evi olmamali.
    Panelde jest ve kol dugmeleri dokunmatikte tiklanmiyordu: sebep cift
    dokunusla zoom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
    [app_main.cpp, pati_panel.cpp]
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
